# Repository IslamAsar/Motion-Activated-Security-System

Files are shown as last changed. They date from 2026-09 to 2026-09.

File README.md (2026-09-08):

<div align="center">

# 🔐 Motion-Activated Security System

### Arduino-based intrusion detection with live OLED telemetry

 


</div>

> Embedded Systems Hands-On Project | Maker Internship Program 2026
>
> **ITIDA · EME Innovation Labs — Giza · Supervised by Origin Integrated Systems (OIS)**

A dual-state **ARMED / DISARMED** Arduino security system combining PIR motion sensing, ambient light monitoring, hardware-interrupt mode switching, a servo-actuated deadbolt, a piezo buzzer, an RGB status LED, and a live SSD1306 OLED telemetry dashboard.

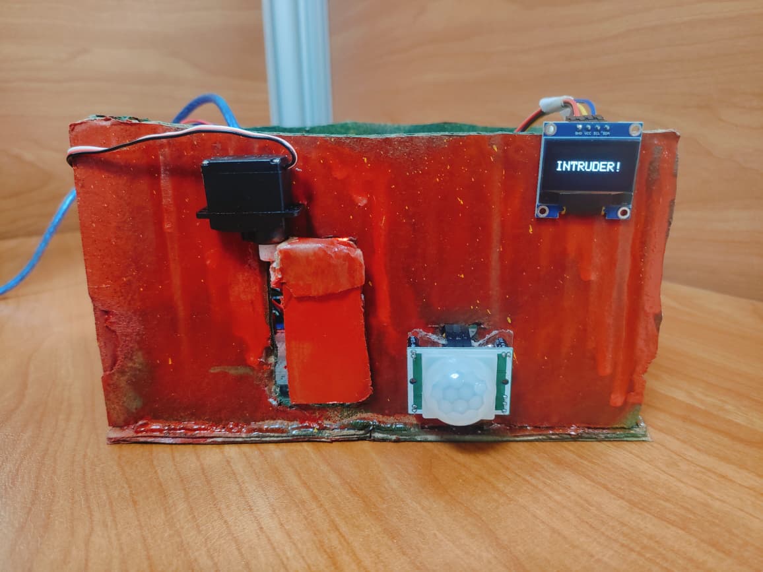
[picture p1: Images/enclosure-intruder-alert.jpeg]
Enclosure showing intrusion alert


> [!IMPORTANT]
> In **ARMED** mode, motion activates the red alert LED, locks the servo deadbolt, sounds a 1 kHz siren, and displays `INTRUDER!` on the OLED.

## 👥 Team

- Islam Ahmed Nabil Asar
- Mai Mohamed Fawzy Ali
- Abdallah Hassan Abu Al-Naaman

## 🧭 Overview

The system monitors a protected area using a PIR sensor and reacts differently depending on whether it is **ARMED** or **DISARMED**:

- 🚨 **ARMED** — any detected motion triggers a full intrusion response: red LED on, deadbolt servo locks to 90°, a continuous 1 kHz siren sounds, and the OLED shows a large `INTRUDER!` warning. The motion counter increments and the alert holds for 3 seconds before resetting.
- 🟢 **DISARMED** — the system idles safely (green LED on, deadbolt open). If ambient light drops below 20% ("Night Mode"), any detected motion triggers a courtesy double-beep instead of an alarm.

Mode switching is handled by the debounced `ButtonSensor` class, and every physical component is represented by an encapsulated C++ class.

## ✨ Features

- 🔁 **Dual operational states** (ARMED / DISARMED) toggled via the debounced button sensor on D3
- 📈 **Rising-edge motion discrimination** — counts each motion event once, even during sustained PIR presence
- 💡 **Adaptive day/night light logic** — LDR reading mapped to a 0–100% illumination scale, with a Night Mode threshold below 20%
- 🚨 **Multi-modal intrusion alarm** — simultaneous red LED, servo deadbolt lock, 1 kHz siren, and OLED warning splash
- 📟 **Live OLED telemetry** — current state, motion count, light %, and night-mode status
- 🛡️ **Interrupt-driven input** — D3 falling-edge interrupt with a 50 ms `millis()`-based debounce lockout
- 🧹 **State-resetting event log** — motion counter resets automatically each time the system is armed

## 🔧 Hardware / Bill of Materials

| Component | Interface | Pin | Role |
|---|---|---|---|
| Arduino Uno R3 (ATmega328P) | Core controller | — | Central processing & timing |
| HC-SR501 PIR motion sensor | Digital input | D2 | Human motion detection |
| Tactile push button | Digital input (`INPUT_PULLUP`) | D3 | Mode toggle |
| Passive piezo buzzer | PWM / `tone()` | D8 | Alarm siren & courtesy beeps |
| SG90 micro servo | PWM servo control | D10 | Electronic deadbolt (0°–90°) |
| RGB LED — green channel | Digital output | D11 | Disarmed / safe indicator |
| RGB LED — red channel | Digital output | D12 | Intrusion alert indicator |
| KY-018 LDR photoresistor module | Analog input | A0 | Ambient light level |
| 0.96" SSD1306 OLED (128×64) | I2C | SDA: A4, SCL: A5 (addr `0x3C`) | Real-time telemetry dashboard |
| Breadboard & jumper wires | — | — | Prototyping backplane |

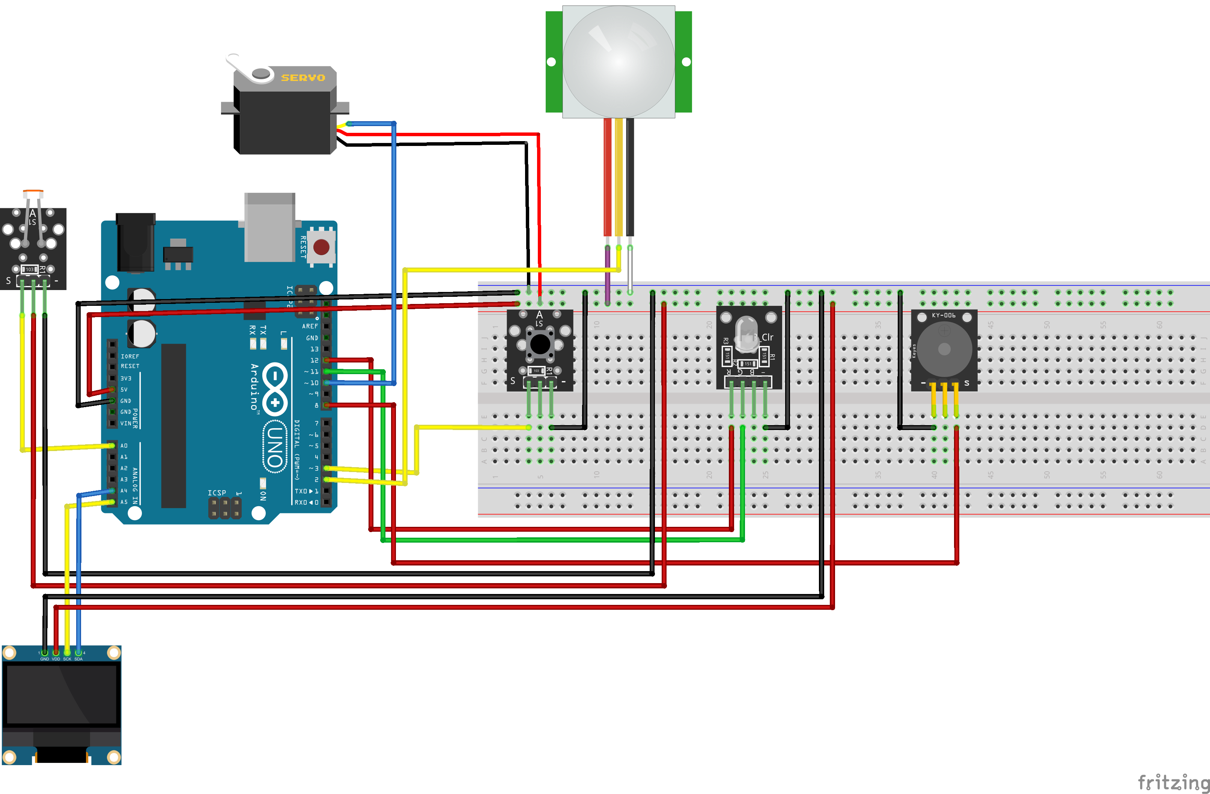
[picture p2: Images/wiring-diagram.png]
Complete wiring diagram

*Complete hardware interfacing and wiring diagram (Fritzing).*

### 📝 Design notes

- The push button uses the ATmega328P's internal pull-up (`INPUT_PULLUP`), giving a deterministic HIGH-idle state and a clean falling edge to GND on press — no external pull-up resistor or debounce hardware required.
- The OLED shares the Arduino's I2C bus (`SDA`/`SCL`) alongside VCC/GND, relying on the Wire library's internal pull-ups.
- The LDR forms a voltage divider with a 10 kΩ resistor; its analog reading is inverted and linearly mapped to a 0–100% scale (`map(readValue(), 0, 1023, 100, 0)`).
- The servo represents an open perimeter at 0° and a deployed deadbolt at 90°, driven by the standard `Servo.h` library at 50 Hz.

## 📊 System Behavior (Truth Table)

| State | PIR | Night Mode (<20%) | Red LED | Green LED | Servo | Buzzer | OLED |
|---|---|---|---|---|---|---|---|
| DISARMED | No motion | OFF | LOW | HIGH | 0° | Silent | Dashboard |
| DISARMED | Motion | OFF | LOW | HIGH | 0° | Silent | Dashboard |
| DISARMED | Motion | ON | LOW | HIGH | 0° | Double beep (1.5 kHz, 100 ms) | Dashboard |
| ARMED | No motion | Any | LOW | LOW | 0° (idle) | Silent | Dashboard |
| ARMED | Motion | Any | HIGH | LOW | 90° (locked) | Continuous siren (1 kHz, 3 s) | `INTRUDER!` |

## 🧠 Firmware Architecture

The firmware is a deterministic finite-state machine with two states, `DISARMED` and `ARMED`, coordinated in `Motion_Security.ino`. The hardware classes are declared in `.h` files and implemented in matching `.cpp` files:

- **Polymorphic interfaces** — abstract `HardwareComponent`, `Sensor`, and `Actuator` bases define virtual lifecycle, input, and output methods.
- **Sensors** — `MotionSensor`, `ButtonSensor`, and `LightSensor` encapsulate the PIR, button, and LDR interfaces.
- **Actuators** — `LedActuator`, `Buzzer`, and `ServoLock` encapsulate the indicator LEDs, buzzer, and deadbolt servo. `OledDisplay` owns the SSD1306 display.
- **Main loop** — reads sensor objects through their public APIs, detects PIR rising edges, and dispatches actuator behavior through the common abstractions.
- **Non-blocking timing** — the three-second intrusion hold and night-mode courtesy beep use `millis()` timestamps, so the button remains responsive during an active alarm.

### UML Class Diagram

```mermaid
classDiagram
	class HardwareComponent {
		<<abstract>>
		+~HardwareComponent()
		+begin() void
	}
	class Sensor {
		<<abstract>>
		+readValue() int
	}
	class Actuator {
		<<abstract>>
		+activate() void
		+deactivate() void
	}
	class MotionSensor {
		-_pin uint8_t
		+MotionSensor(sensorPin)
		+begin() void
		+readValue() int
		+isMotionDetected() bool
	}
	class ButtonSensor {
		-_pin uint8_t
		-_pressed volatile bool
		-_lastInterruptAt volatile unsigned long
		-_instance ButtonSensor*
		-handleInterrupt() void
		+ButtonSensor(buttonPin)
		+begin() void
		+readValue() int
		+wasPressed() bool
	}
	class LightSensor {
		-_pin uint8_t
		+LightSensor(sensorPin)
		+begin() void
		+readValue() int
		+readPercent() int
	}
	class LedActuator {
		-_pin uint8_t
		+LedActuator(ledPin)
		+begin() void
		+activate() void
		+deactivate() void
	}
	class Buzzer {
		-_pin uint8_t
		-_courtesyStep uint8_t
		-_courtesyStartedAt unsigned long
		+Buzzer(buzzerPin)
		+begin() void
		+activate() void
		+deactivate() void
		+courtesyBeep(now) void
		+update(now) void
	}
	class ServoLock {
		-_pin uint8_t
		-_servo Servo
		+ServoLock(servoPin)
		+begin() void
		+activate() void
		+deactivate() void
	}
	class OledDisplay {
		-_display Adafruit_SSD1306
		+OledDisplay()
		+begin() void
		+updateStatus(...) void
		+showAlert() void
	}
	class Servo {
		<<external library>>
	}
	class Adafruit_SSD1306 {
		<<external library>>
	}

	HardwareComponent <|-- Sensor
	HardwareComponent <|-- Actuator
	Sensor <|-- MotionSensor
	Sensor <|-- ButtonSensor
	Sensor <|-- LightSensor
	Actuator <|-- LedActuator
	Actuator <|-- Buzzer
	Actuator <|-- ServoLock
	HardwareComponent <|-- OledDisplay
	ServoLock *-- Servo
	OledDisplay *-- Adafruit_SSD1306
```

### 📚 Required Libraries

- [`Adafruit_GFX`](https://github.com/adafruit/Adafruit-GFX-Library)
- [`Adafruit_SSD1306`](https://github.com/adafruit/Adafruit_SSD1306)
- `Servo` (bundled with the Arduino IDE)
- `Wire` (bundled with the Arduino IDE)

Install the Adafruit libraries via **Arduino IDE → Sketch → Include Library → Manage Libraries**, or through PlatformIO's library manager.

## 🧪 Breadboard Prototype

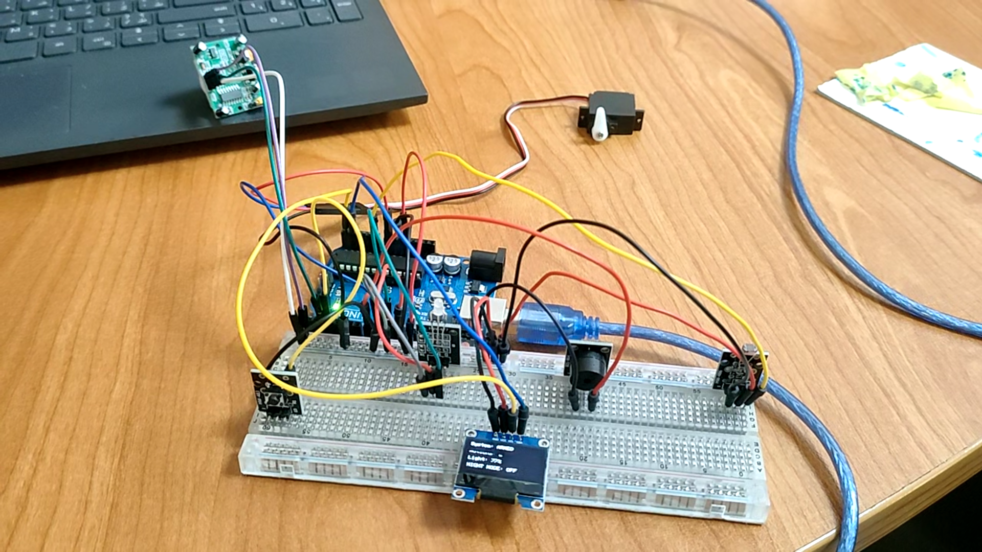
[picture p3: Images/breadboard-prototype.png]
Breadboard prototype

*Bench prototype assembled on a solderless breadboard, used to validate wiring and firmware before enclosure integration.*

## 🚀 Getting Started

1. 🔌 Wire the components as described in the BOM and pin table above (see the Fritzing schematic in the project report for the full wiring diagram).
2. 📚 Install the required libraries listed above.
3. 📂 Open `Motion_Security.ino` in the Arduino IDE.
4. ⚙️ Select **Arduino Uno** as the board and the correct serial port.
5. ⬆️ Upload the sketch.
6. 🖥️ Open the Serial Monitor at **9600 baud** to view motion event logs.
7. 🔘 Press the push button on D3 to toggle between ARMED and DISARMED.

## ✅ Verification

The design was validated in **Proteus 8 Professional** across armed/disarmed states, day/night lighting, and motion events before physical assembly, then confirmed on a breadboard prototype. All test cases (intrusion under daylight and night mode, disarmed monitoring, and night-mode courtesy alerts) passed with full behavioral match between simulation and hardware.

### Bench testing highlights

- ✅ 50 ms software debounce achieved 100% reliability across 50+ button presses with zero spurious toggles.
- ✅ Rising-edge detection incremented the motion counter exactly once per PIR entry, even with sustained presence.
- ✅ Alarm actuators (servo, siren, LED, OLED override) responded within ~15 ms of PIR trigger detection.

| DISARMED (Proteus) | INTRUDER ! (Proteus) |
|---|---|
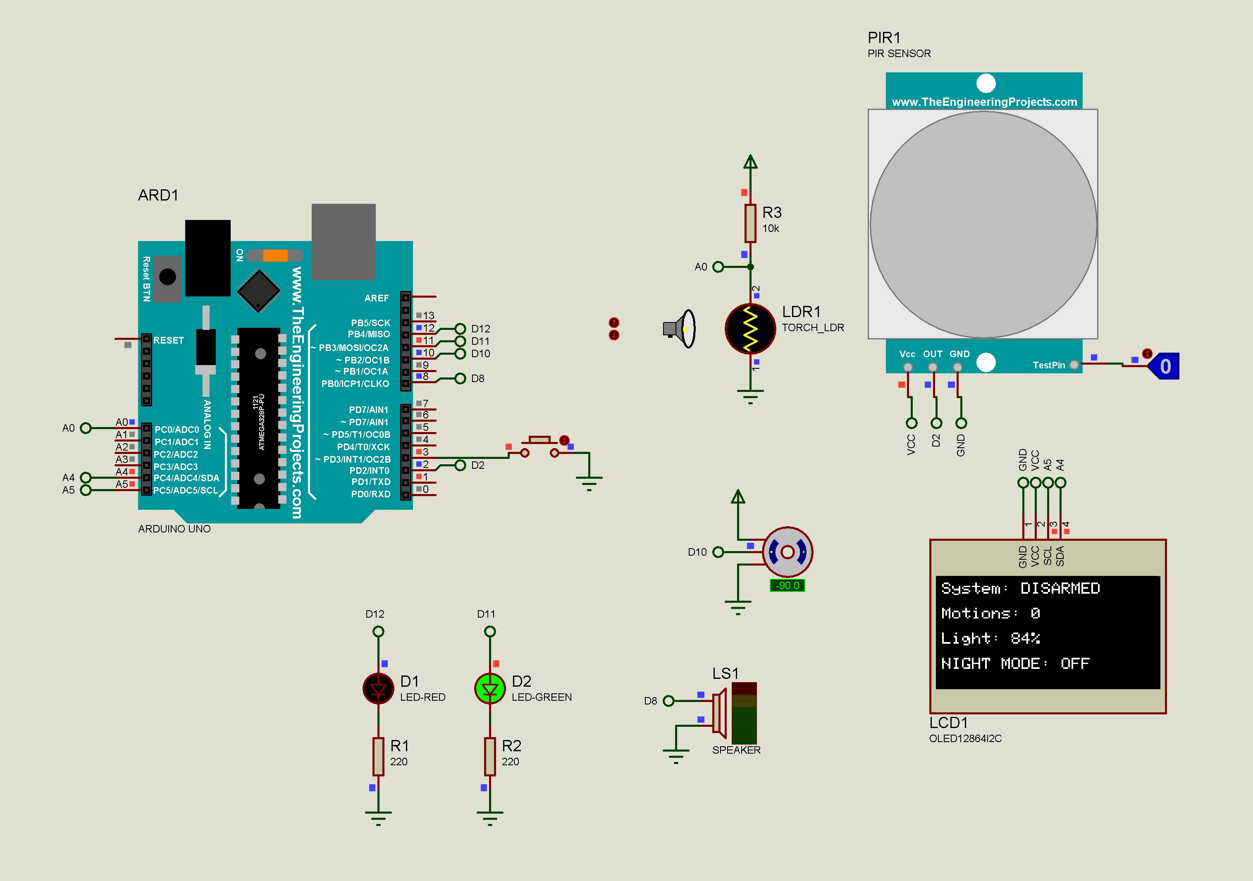
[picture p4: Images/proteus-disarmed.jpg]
Disarmed state simulation
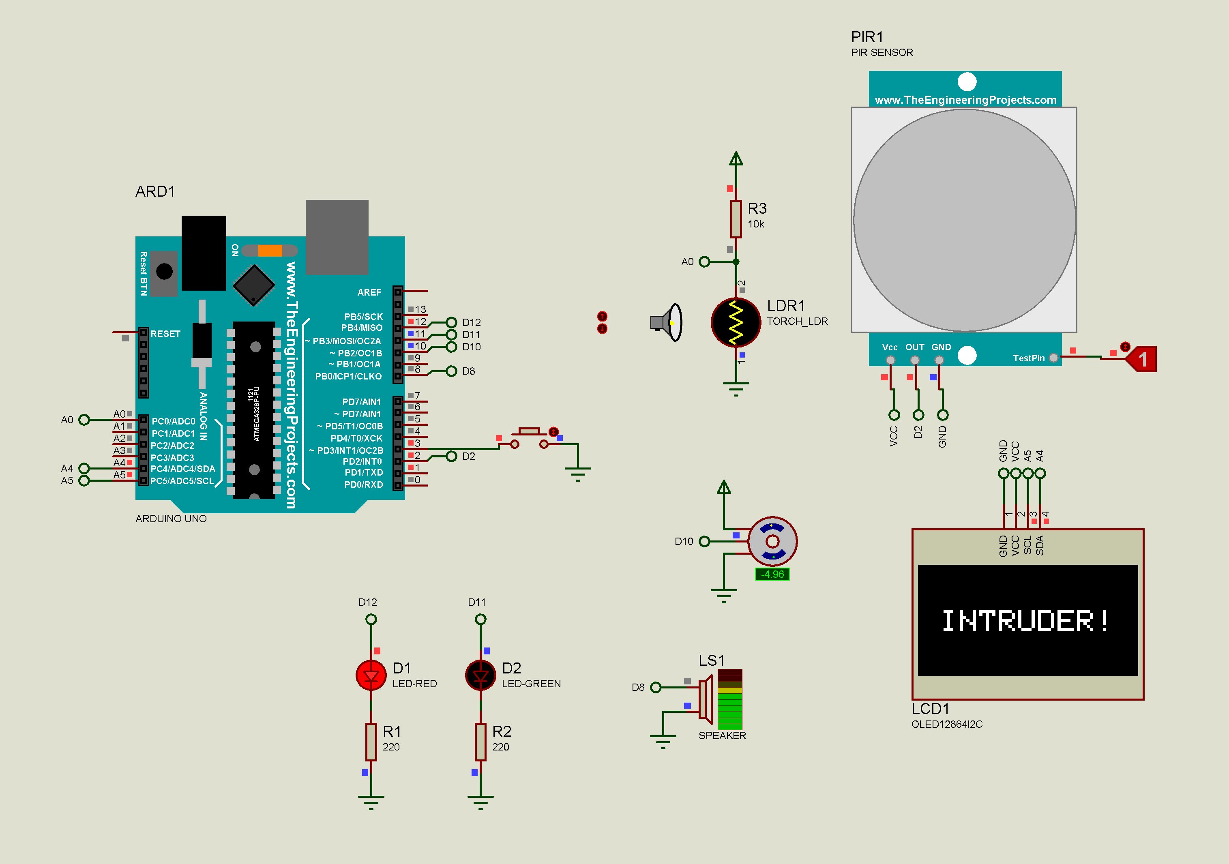
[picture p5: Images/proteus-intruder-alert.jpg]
Intruder alert simulation
|  |  |

## 🏠 Final Build

The finished system was housed in a painted enclosure with the PIR sensor, deadbolt servo, and OLED dashboard mounted on the front face.

| Interior wiring | Disarmed (idle) | Intrusion alert |
|---|---|---|
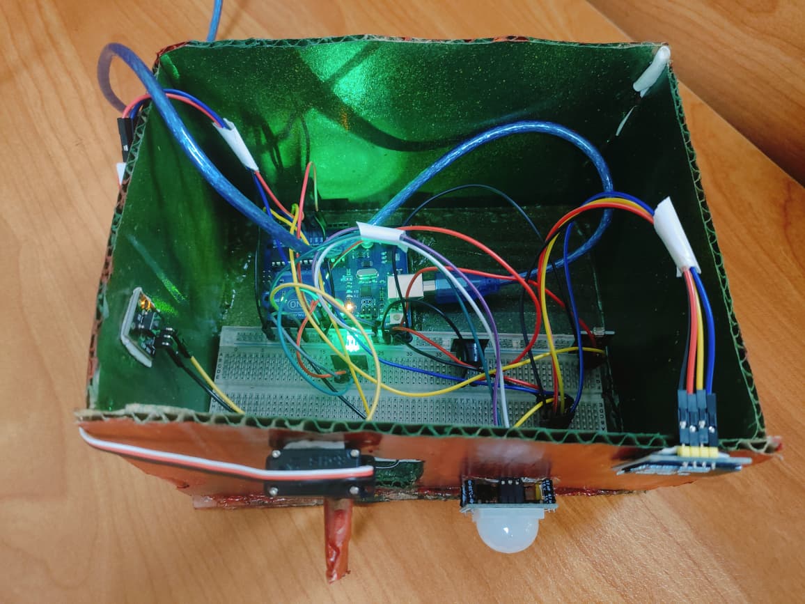
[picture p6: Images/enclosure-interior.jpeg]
Enclosure interior wiring
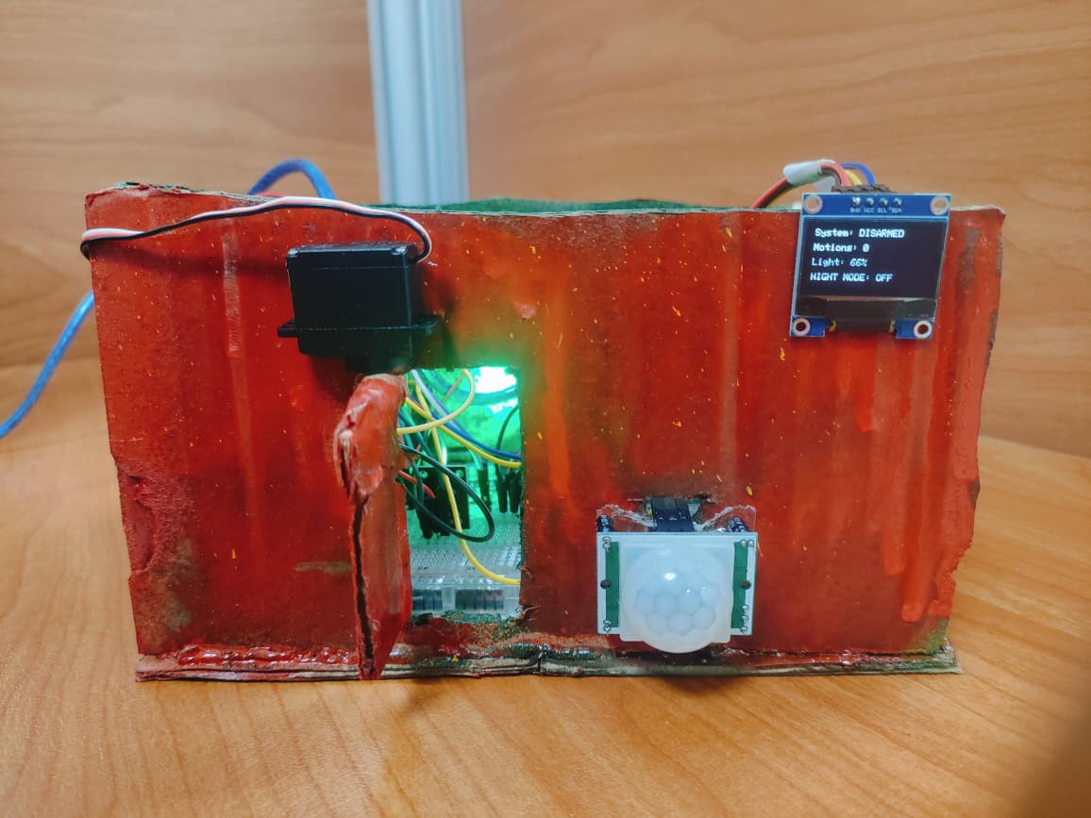
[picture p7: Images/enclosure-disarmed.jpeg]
Enclosure disarmed
|  |  | Enclosure intruder alert |

## 🔭 Future Enhancements

- ☁️ **IoT cloud telemetry** — migrate to an ESP32 for Wi-Fi/MQTT event streaming and remote dashboard monitoring.
- 🔋 **Power backup** — add a lithium-ion UPS circuit for operation during mains power loss.

## 📁 Repository Contents

```
.
├── Motion_Security/            # Arduino firmware source folder
│   ├── Motion_Security.ino     # Main Arduino sketch
│   └── *.h / *.cpp             # Encapsulated hardware classes
├── Images/                     # Wiring diagram, prototype, and enclosure photos
├── Schematic.fzz               # Fritzing wiring/breadboard project
├── Simulation.pdsprj           # Proteus 8 simulation project
├── README.md                   # Project documentation
```

## 🙏 Acknowledgements

Developed as part of the **Maker Internship Program 2026 — Embedded Systems Track**, hosted by **ITIDA - EME Innovation Labs (Giza)** and operated/supervised by **Origin Integrated Systems (OIS)**.

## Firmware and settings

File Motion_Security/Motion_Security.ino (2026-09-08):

#include "Actuators.h"
#include "Sensors.h"

// The controller has two operating modes, selected with the push button.
enum SystemState { DISARMED, ARMED };

// Hardware objects keep pin access and device-specific behavior encapsulated.
MotionSensor motionSensor(2);
ButtonSensor modeButton(3);
LightSensor lightSensor(A0);
Buzzer alarmBuzzer(8);
ServoLock lockServo(10);
LedActuator greenLed(11);
LedActuator redLed(12);
OledDisplay display;

Sensor* sensors[] = { &motionSensor, &modeButton, &lightSensor };
Actuator* actuators[] = { &alarmBuzzer, &lockServo, &greenLed, &redLed };

// These values belong to the application state, not to individual devices.
SystemState currentState = DISARMED;
bool lastPirState = LOW;
bool alarmActive = false;
unsigned long alarmStartedAt = 0;
int motionCount = 0;

// Start all alarm outputs together and keep the start time for non-blocking timing.
void startAlarm(unsigned long now, int lightPercent) {
  alarmActive = true;
  alarmStartedAt = now;
  redLed.activate();
  lockServo.activate();
  alarmBuzzer.activate();
  display.showAlert();
  motionCount++;
  Serial.print("[ALERT] Motion @");
  Serial.print(now);
  Serial.print("ms | Light:");
  Serial.print(lightPercent);
  Serial.println("%");
}

// Return every alarm output to its safe idle state.
void stopAlarm() {
  alarmActive = false;
  redLed.deactivate();
  lockServo.deactivate();
  alarmBuzzer.deactivate();
}

void setup() {
  Serial.begin(9600);

  // Use the common base-class API to initialize all sensors and actuators.
  for (Sensor* sensor : sensors) {
    sensor->begin();
  }
  for (Actuator* actuator : actuators) {
    actuator->begin();
  }
  display.begin();
  lockServo.deactivate();
  alarmBuzzer.deactivate();
}

void loop() {
  unsigned long now = millis();
  int lightPercent = lightSensor.readPercent();
  bool isNightMode = lightPercent < 20;
  bool currentPirState = motionSensor.isMotionDetected();
  // A rising edge counts one motion event, even if the PIR stays HIGH.
  bool pirTriggered = currentPirState && !lastPirState;

  if (modeButton.wasPressed()) {
    // Disarming also cancels an active alarm immediately.
    currentState = (currentState == DISARMED) ? ARMED : DISARMED;
    motionCount = (currentState == ARMED) ? 0 : motionCount;
    stopAlarm();
  }

  if (currentState == ARMED) {
    greenLed.deactivate();
    if (pirTriggered && !alarmActive) {
      startAlarm(now, lightPercent);
    }
    // millis() keeps the loop responsive while the three-second alarm is active.
    if (alarmActive && now - alarmStartedAt >= 3000UL) {
      stopAlarm();
    }
    if (!alarmActive) {
      display.updateStatus("ARMED", lightPercent, isNightMode, motionCount);
    }
  } else {
    greenLed.activate();
    redLed.deactivate();
    lockServo.deactivate();
    if (isNightMode && pirTriggered) {
      // The courtesy beep has its own non-blocking sequence in Buzzer.
      alarmBuzzer.courtesyBeep(now);
    }
    alarmBuzzer.update(now);
    display.updateStatus("DISARMED", lightPercent, isNightMode, motionCount);
  }
  lastPirState = currentPirState;
}

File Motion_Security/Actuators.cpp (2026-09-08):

#include "Actuators.h"

// ---------------- LedActuator ----------------
LedActuator::LedActuator(uint8_t ledPin) : _pin(ledPin) {}

void LedActuator::begin() {
  pinMode(_pin, OUTPUT);
  deactivate();
}

void LedActuator::activate() {
  digitalWrite(_pin, HIGH);
}

void LedActuator::deactivate() {
  digitalWrite(_pin, LOW);
}

// ---------------- Buzzer ----------------
Buzzer::Buzzer(uint8_t buzzerPin)
  : _pin(buzzerPin), _courtesyStep(0), _courtesyStartedAt(0) {}

void Buzzer::begin() {
  pinMode(_pin, OUTPUT);
  deactivate();
}

void Buzzer::activate() {
  tone(_pin, 1000);
}

void Buzzer::deactivate() {
  noTone(_pin);
  _courtesyStep = 0;
}

void Buzzer::courtesyBeep(unsigned long now) {
  // Start only once; update() advances the two-tone sequence on later loops.
  if (_courtesyStep == 0) {
    _courtesyStep = 1;
    _courtesyStartedAt = now;
    tone(_pin, 1500);
  }
}

void Buzzer::update(unsigned long now) {
  // Each step is timed without delay(), keeping button and PIR handling responsive.
  if (_courtesyStep == 1 && now - _courtesyStartedAt >= 100UL) {
    noTone(_pin);
    _courtesyStep = 2;
    _courtesyStartedAt = now;
  } else if (_courtesyStep == 2 && now - _courtesyStartedAt >= 50UL) {
    tone(_pin, 1500);
    _courtesyStep = 3;
    _courtesyStartedAt = now;
  } else if (_courtesyStep == 3 && now - _courtesyStartedAt >= 100UL) {
    deactivate();
  }
}

// ---------------- ServoLock ----------------
ServoLock::ServoLock(uint8_t servoPin) : _pin(servoPin) {}

void ServoLock::begin() {
  _servo.attach(_pin);
  deactivate();
}

void ServoLock::activate() {
  _servo.write(90);
}

void ServoLock::deactivate() {
  _servo.write(0);
}

// ---------------- OledDisplay ----------------
OledDisplay::OledDisplay()
  : _display(128, 64, &Wire, -1) {}

void OledDisplay::begin() {
  // Halt here if the display is not connected; the dashboard is required by the system.
  if (!_display.begin(SSD1306_SWITCHCAPVCC, 0x3C)) {
    Serial.println(F("SSD1306 allocation failed"));
    for (;;) {}
  }
  _display.clearDisplay();
  _display.display();
}

void OledDisplay::updateStatus(const String& status, int light, bool night,
                               int motions) {
  // Redraw the compact telemetry dashboard once per main-loop iteration.
  _display.clearDisplay();
  _display.setTextSize(1);
  _display.setTextColor(SSD1306_WHITE);
  _display.setCursor(0, 0);
  _display.print(F("System: "));
  _display.println(status);
  _display.setCursor(0, 16);
  _display.print(F("Motions: "));
  _display.println(motions);
  _display.setCursor(0, 32);
  _display.print(F("Light: "));
  _display.print(light);
  _display.println(F("%"));
  _display.setCursor(0, 48);
  _display.println(night ? F("NIGHT MODE: ON") : F("NIGHT MODE: OFF"));
  _display.display();
}

void OledDisplay::showAlert() {
  // The alert screen temporarily replaces the normal telemetry dashboard.
  _display.clearDisplay();
  _display.setTextSize(2);
  _display.setTextColor(SSD1306_WHITE);
  _display.setCursor(10, 25);
  _display.println(F("INTRUDER!"));
  _display.display();
}

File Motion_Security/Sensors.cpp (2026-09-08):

#include "Sensors.h"

// ---------------- MotionSensor ----------------
MotionSensor::MotionSensor(uint8_t sensorPin) : _pin(sensorPin) {}

void MotionSensor::begin() {
  pinMode(_pin, INPUT);
}

int MotionSensor::readValue() {
  return digitalRead(_pin);
}

bool MotionSensor::isMotionDetected() {
  return readValue() == HIGH;
}

// ---------------- ButtonSensor ----------------
ButtonSensor* ButtonSensor::_instance = nullptr;

ButtonSensor::ButtonSensor(uint8_t buttonPin)
  : _pin(buttonPin), _pressed(false), _lastInterruptAt(0) {
  _instance = this;
}

void ButtonSensor::begin() {
  pinMode(_pin, INPUT_PULLUP);
  _pressed = false;
  _lastInterruptAt = millis();
  attachInterrupt(digitalPinToInterrupt(_pin), ButtonSensor::handleInterrupt, FALLING);
}

int ButtonSensor::readValue() {
  return digitalRead(_pin);
}

bool ButtonSensor::wasPressed() {
  noInterrupts();
  bool pressed = _pressed;
  _pressed = false;
  interrupts();
  return pressed;
}

void ButtonSensor::handleInterrupt() {
  if (_instance == nullptr) {
    return;
  }

  unsigned long now = millis();
  if (now - _instance->_lastInterruptAt >= 50UL) {
    _instance->_pressed = true;
    _instance->_lastInterruptAt = now;
  }
}

// ---------------- LightSensor ----------------
LightSensor::LightSensor(uint8_t sensorPin) : _pin(sensorPin) {}

void LightSensor::begin() {}

int LightSensor::readValue() {
  return analogRead(_pin);
}

int LightSensor::readPercent() {
  // The voltage-divider reading is inverted: lower ADC values mean brighter light.
  return map(readValue(), 0, 1023, 100, 0);
}

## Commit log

2026-09-07 Upolad project files
    [Schematic.fzz]
2026-09-08 Restore interrupt-driven button handling
